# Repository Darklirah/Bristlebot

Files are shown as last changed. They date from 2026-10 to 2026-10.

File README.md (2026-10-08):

# One-of-a-Kind Mars Rover

> Dieses Projekt wurde mit Unterstützung von [Claude Code](https://claude.com/claude-code) entwickelt.

Linienfolgender, programmierbarer Zahnbürsten-Roboter auf ESP32, aufgebaut
auf einer eigenen Platine. Jedes Exemplar bekommt einen eigenen Namen und
ein eigenes WLAN (`MarsRover_Petra`), damit mehrere nebeneinander fahren
können.

> **Verwandt mit dem Bristlebot.** Der Mars Rover fährt nach demselben
> Prinzip wie ein *Bristlebot* — jener kleine Vibrationsläufer aus einem
> Zahnbürstenkopf, einem Unwuchtmotor und einer Knopfzelle, der über den
> Tisch summt. Er kann nur deutlich mehr: **zwei** Antriebe statt einem,
> damit er überhaupt lenken kann, zwei Augen für die Linie unter sich,
> Steuerung vom Handy und selbst geschriebene Fahrprogramme. Ein Bristlebot
> fährt, wohin er will — dieser hier fährt, wohin du willst.

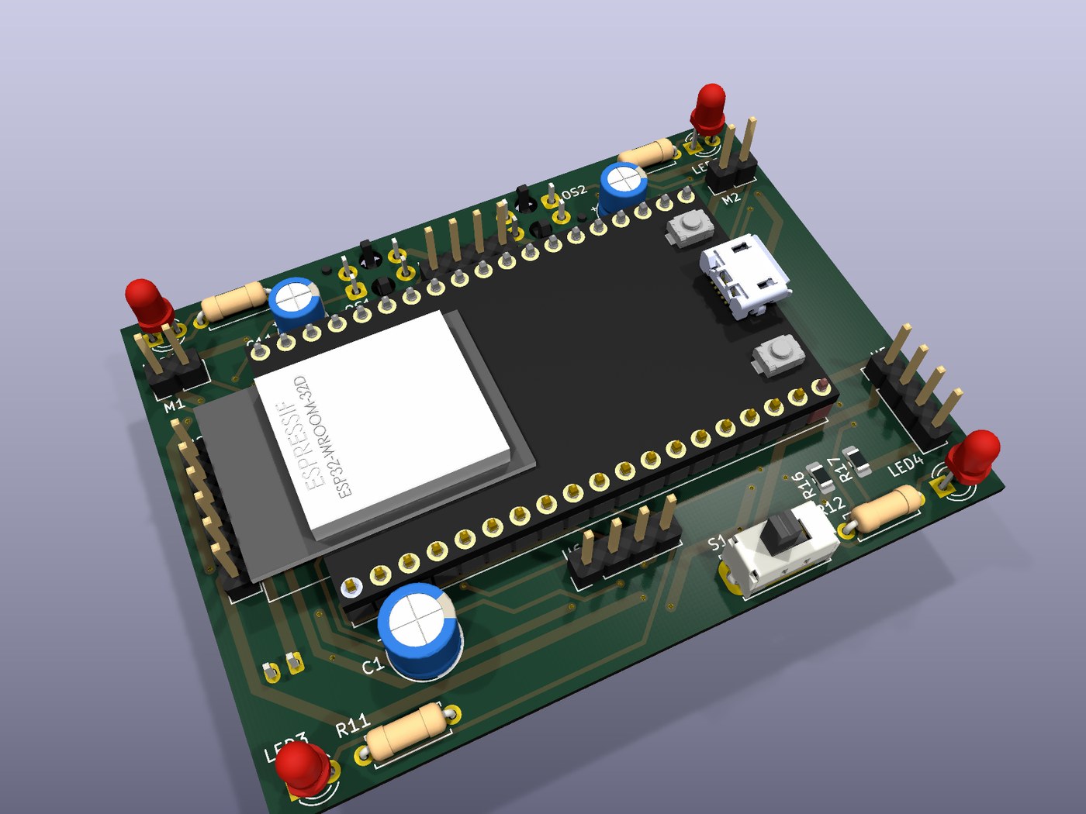
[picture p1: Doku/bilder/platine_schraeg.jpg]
Die fertig geroutete Platine, schräg von oben


*Die eigene Platine, 70 × 52 mm, zweilagig. Das ESP32-DevKit steckt quer auf
Buchsenleisten; links und rechts stehen Laderegler und Step-Up-Wandler
senkrecht als „Finnen". Weitere Ansichten mit Erklärung in
[Doku/04 §7](Doku/04_PCB-Layout-Empfehlung.md#7--so-ist-sie-geworden).*

**[→ Firmware direkt im Browser installieren](https://darklirah.github.io/One-of-a-Kind-Mars-Rover/)**

Die ausführliche Projektbeschreibung samt Programmier-Kapitel steht in
[Doku/00_Projektbeschreibung.md](Doku/00_Projektbeschreibung.md).

Zwei Vibrationsmotoren treiben zwei getrennte Borstenfelder an;
differentielle Vibrationsintensität lenkt. Zwei Reflexkoppler lesen die Linie,
ein PD-Regler hält ihn darauf. Gesteuert wird er über einen WLAN-Access-Point,
den der ESP32 selbst aufspannt — die Bedienoberfläche liefert er gleich mit.

**Status:** Hardware entworfen und geprüft, Firmware vollständig und
**fehlerfrei kompiliert** (0 Fehler, 0 Warnungen mit `-Wall`;
RAM 15,2 %, Flash 69,8 %) — **aber noch nie auf echter Hardware gelaufen.**

---

## Eckdaten

| | |
|---|---|
| Rechenkern | ESP32 DevKit V1, 30-Pin, gesteckt |
| Antrieb | 2× Vibrationsmotor 3 V über AO3400A Logik-MOSFET, 20 kHz PWM (LEDC) |
| Sensorik | 2× TCRT5000 analog an ADC1 (GPIO 34/35) |
| Lage | MPU-6050 am I²C: Drehen nach Winkel, Kurs halten, Kippschutz |
| Abstand | VL53L0X auf einem Mast: Hindernisse erkennen und umfahren |
| Anzeige | 4 LEDs: gelb vorne = Lenkrichtung, rot hinten = Status |
| Energie | LiPo 500 mAh, TP4056 über USB-C, MT3608 auf 5 V |
| Laufzeit | ≈ 1,2 h fahrend, ≈ 2,0 h Standby |
| Betriebsarten | Linie folgen · selbst fahren · Fahrprogramm |
| Fahrprogramme | 4 Speicherplätze im Flash, je 48 Schritte, Baukasten-Editor |
| Fernsteuerung | WLAN-AP + eigene Web-App, läuft auf iPhone **und** Android im Browser |
| Materialkosten | ≈ 26,50 € im Einzelstück |
| Masse | ≈ 40 g (größtes technisches Risiko, siehe Doku) |

## Bedienung in drei Schritten

1. Einschalten
2. Am Handy ins WLAN **`MarsRover_…`**, Passwort **`marsrover`**
3. Die Seite klappt von selbst auf — falls nicht: **`http://192.168.4.1`**

Nach dem Einschalten ist der Roboter **gesperrt**. Erst *Freigeben* in der App
lässt die Motoren laufen.

---

## Dokumentation

| Datei | Inhalt |
|---|---|
| [00 Projektbeschreibung](Doku/00_Projektbeschreibung.md) | Was das Projekt ist, alle Funktionen, ausführliches Kapitel zum Programmieren |
| [01 Schaltplan-Review](Doku/01_Schaltplan-Review.md) | Prüfung des Entwurfs: 5 Blocker, 9 Verbesserungen, Änderungsliste |
| [02 SMD vs. THT](Doku/02_SMD-vs-THT-Wirtschaftlichkeit.md) | Kostenvergleich bei 1/10/100 Stück, Massebudget, Laufzeitrechnung |
| [03 Stückliste](Doku/03_Stueckliste-BOM.md) | Vollständige BOM mit Bauteilkürzeln, Preisen und Einkaufsfallen |
| [04 PCB-Layout](Doku/04_PCB-Layout-Empfehlung.md) | Fertigungsparameter, Masseführung, Platzierung, Mechanik |
| [05 Pinbelegung](Doku/05_Pinbelegung.md) | Pinplan mit Begründungen, freie Pins, Vorzeichenkonventionen |
| [06 Fernsteuerung](Doku/06_Fernsteuerung-App.md) | Warum WLAN und nicht Bluetooth, Protokoll, fertige Apps als Rückfallebene |
| [07 Inbetriebnahme](Doku/07_Inbetriebnahme-und-Tuning.md) | Schrittweiser Aufbau, Kalibrierung, Reglerabstimmung, Fehlersuche |
| [Netzliste](Hardware/Netzliste.md) | Verbindungsliste als Vorlage für KiCad |
| [Projekt-Log](00_Projekt-Log.md) | Entscheidungen und offene Punkte |

## Firmware

```
Firmware/
  platformio.ini
  MarsRover/
    MarsRover.ino       Zustandsmaschine, PD-Regler, Telemetrie
    Config.h            Pins, Kennwerte, Feature-Flags  <- hier tunen
    RobotState.h        Betriebsart, Phase, Tuningstruktur
    Motors.*            PWM, Kennlinienspreizung, Kickstart, Duty-Begrenzung
    LineSensor.*        Median-Filter, Kalibrierung in NVS
    Leds.*              Blinkmuster
    RemoteControl.*     Access Point, Webserver, WebSocket, Protokoll
    WebUI.h             Bedienoberfläche, komplett inline
```

**Einzige externe Abhängigkeit:** `WebSockets` von Markus Sattler
(„arduinoWebSockets") ≥ 2.4.1. Läuft mit ESP32-Arduino-Core 2.x und 3.x — die
umgestellte LEDC-API wird per `#if` abgefangen.

Board: *ESP32 Dev Module*, 4 MB Flash, Partition *Default 4MB with spiffs*.

---

## Die wichtigsten vier Warnungen

1. **MT3608 vor dem ersten Anschluss des ESP32 im Leerlauf auf 5,00 V trimmen.**
   Die Module kommen mit beliebiger Einstellung, oft über 20 V. Das tötet das
   DevKit sofort.
2. **R_prog am TP4056 tauschen** — Werkszustand 1 A ist für eine 500-mAh-Zelle
   mehr als das Doppelte des Zulässigen. 4,7 kΩ ergibt 255 mA.
3. **USB-C braucht 2× 5,1 kΩ an CC1 und CC2 nach GND**, sonst liefert ein
   USB-C-Netzteil keine Spannung.
4. **Zwei getrennte Borstenfelder, eines unter jedem Motor.** Auf einer
   gemeinsamen Grundplatte mittelt sich die Vibrationsdifferenz weg und der
   Roboter lenkt praktisch nicht.

## Lizenz

[GNU General Public License v3.0](LICENSE)

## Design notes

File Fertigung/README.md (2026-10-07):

# Fertigungsdaten

**Alles in diesem Ordner ist erzeugt.** Die Quelle ist `pcb/MarsRover.kicad_pcb`.
Nach jeder Änderung an der Platine neu erzeugen:

```bash
bash Fertigung/erzeuge_fertigungsdaten.sh
```

Sonst liegen hier Gerber, die nicht mehr zur Platine passen — das ist der
klassische Weg, eine falsche Platine zu bestellen.

Stand: 07.10.2026, DRC 0 Fehler, 0 unverbundene Elemente.

---

## 1 · Was wohin gehört

| Datei | Wofür |
|---|---|
| `MarsRover-gerber.zip` | **Das lädst du beim Leiterplattenhersteller hoch.** Enthält alle Gerber, beide Bohrdateien und die Bohrpläne |
| `MarsRover-pastenschablone.zip` | Für den Schablonenhersteller: `F_Paste` + `Edge_Cuts` als Gerber, dazu DXF und SVG |
| `MarsRover-stueckliste.csv` | Einkaufsliste, nach Wert und Bauform gruppiert |
| `MarsRover-bestueckung.csv` | Bestückungsdaten (Referenz, Wert, Bauform, X, Y, Drehung, Seite) — nur nötig, wenn du maschinell bestücken lässt |
| `MarsRover-platine.step` | 3D-Modell der **nackten** Platine für den Entwurf des Basismoduls |
| `gerber/`, `pastenschablone/` | derselbe Inhalt unverpackt, zum Nachsehen |

Das vollständige 3D-Modell **mit** Bauteilen liegt unter
`local_Step Files/MarsRover-komplett.step` und bleibt lokal: es enthält
Fremdmodelle aus den KiCad- und Espressif-Bibliotheken, die nicht unsere zum
Weitergeben sind.

---

## 2 · Bestellparameter

| | |
|---|---|
| Lagen | **2** |
| Maße | **70 × 52 mm** |
| Dicke | **1,0 mm** — nicht 1,6 mm, das spart gut 4 g, und Masse ist auf diesem Gerät das Hauptproblem |
| Kupfer | 35 µm (1 oz) |
| Dünnste Leiterbahn | **0,40 mm** |
| Kleinster Abstand | **0,20 mm** |
| Durchkontaktierungen | 91 Stück: 0,8/0,4 mm (88×), 0,7/0,4 (2×), 0,6/0,4 (1×) |
| Kleinste Bohrung | **0,40 mm** (Durchkontaktierungen), 0,75 mm bei Bauteilen |
| Nicht durchkontaktierte Löcher | 6 (Mechanik von OS1/OS2 und S1) |
| Oberfläche | **noch nicht entschieden** — siehe unten |
| Lötstopp / Siebdruck | freie Wahl, elektrisch egal |
| Masseanbindung | **Wärmefallen**, Spalt 0,4 mm, vier Stege à 0,5 mm |

Diese Werte liegen alle im **Standardprozess** der günstigen Fertiger; nichts
davon löst einen Aufpreis aus.

> **Eine Entscheidung steht noch aus: die Oberfläche.** HASL ist am billigsten,
> ENIG kostet wenige Euro mehr und hat eine ebene Oberfläche. Auf dieser
> Platine sitzen 21 SMD-Bauteile, die über eine Pastenschablone bestückt
> werden — dafür ist eine ebene Fläche besser, weil HASL eine unregelmäßig
> dicke Lotbeule auf jedem Pad hinterlässt und die Schablone darauf kippelt.
> Bei 0805 und SOT-23 geht beides; bei ENIG geht es sicherer.

---

## 3 · Pastenschablone

Nur für die **Oberseite**. Auf der Unterseite sitzen nur die beiden TCRT5000
und der Akkustecker, und die sind bedrahtet — `B_Paste` ist deshalb leer.

- **44 Öffnungen**, verteilt auf 21 Bauteile: 9 Kondensatoren und 10
  Widerstände in 0805, 2 MOSFET in SOT-23.
- Rahmenlos bestellen (Framework/Frameless), Dicke **0,12 mm**. Das ist für
  0805 und SOT-23 der übliche Wert; dünner braucht man erst ab 0,5-mm-Raster.

---

## 3a · Wärmefallen an der Massefläche

Die Massefläche auf B.Cu hängt **nicht fest** an den Pads, sondern über
Wärmefallen: sie hält 0,4 mm Abstand zum Pad und greift mit vier Stegen von
0,5 mm Breite darauf zu.

**Warum:** eine 70 × 52 mm große Kupferfläche zieht beim Handlöten die Wärme
schneller ab, als ein Lötkolben sie nachliefert. Das Ergebnis sind kalte
Lötstellen, die beim Messen oft noch leitend wirken und erst bei Vibration
ausfallen — auf diesem Gerät also garantiert.

**Elektrisch kostet das nichts:** vier Stege à 0,5 mm auf 35 µm tragen
zusammen rund 6 A. Der größte Verbraucher auf dieser Masse ist der Step-Up
mit knapp 0,8 A Eingangsstrom, und der hat zwei Pads. Faktor fünfzehn Reserve.

Betroffen sind die **20 bedrahteten** Masse-Pads, die die Fläche direkt
berühren: C1, C11, C12, J2, LED1–LED4, OS1, OS2, U1 (Pins 14/32/38),
U2 (3×), U5 (2×), U6, U7.

Die **16 SMD-Masse-Pads** auf der Oberseite (C2–C10, Q1, Q2, R3, R4, R7, R8,
R17) berühren die Fläche gar nicht — sie hängen über eine kurze Leitung und
eine Durchkontaktierung daran. Dort gibt es nichts zu entlasten, und die
dünne Via-Hülse leitet ohnehin kaum Wärme ab.

---

## 4 · Nullpunkt

Gerber, Bohrdaten und Bestückungsliste benutzen **denselben, absoluten
Nullpunkt** (die Blattkoordinaten von KiCad). Das ist die Bedingung dafür,
dass der Fertiger die drei übereinanderlegen kann. Wenn ein Hersteller einen
Hilfsnullpunkt in einer Platinenecke verlangt, muss er für **alle drei**
Ausgaben umgestellt werden, nicht nur für eine.

---

## 5 · Was das DRC noch meldet, und warum es so bleibt

| Meldung | Anzahl | Warum das in Ordnung ist |
|---|---|---|
| `courtyards_overlap` | 21 | Alle unter U1. Das DevKit steckt auf Buchsenleisten gut 8,5 mm über der Platine; darunter liegt absichtlich alles Flache |
| `pth_inside_courtyard` | 4 | Die Pads von D1/D2, gleicher Grund |
| `lib_footprint_mismatch` | 4 | **Gewollte Abweichungen:** U1 trägt ein 3D-Modell, das die Bibliothek nicht hat, M1/M2 ein Feld „Hinweis" mit der Lötaugen-Begründung. Ohne Auswirkung auf die Fertigung — die Gerber kommen aus der Platinendatei, nicht aus der Bibliothek |

---

## 6 · Vor dem Bestellen prüfen

- [ ] **Reihenabstand des DevKits mit dem Messschieber nachmessen.** Soll:
      **25,4 mm**. Die 30-polige Version hat ein anderes Rastermaß, dann passt
      die Platine nicht. Siehe [Doku/09](../Doku/09_Boardwahl-DevKitC-V4.md)
- [ ] Oberfläche entscheiden (Abschnitt 2)
- [ ] Gerber in einem Betrachter gegenlesen — der Fertiger prüft nicht mit
- [ ] **MT3608 umbauen, bevor er eingelötet wird:** Poti raus, 110 kΩ / 15 kΩ
      rein. Siehe [Doku/07 Schritt 1a](../Doku/07_Inbetriebnahme-und-Tuning.md)

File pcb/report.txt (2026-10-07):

Hinweis: Footprint R1 (Resistor_SMD:R_0805_2012Metric_Pad1.20x1.40mm_HandSolder) aktualisiert: : (keine Änderungen)
Hinweis: Footprint R2 (Resistor_SMD:R_0805_2012Metric_Pad1.20x1.40mm_HandSolder) aktualisiert: : (keine Änderungen)
Hinweis: Footprint R3 (Resistor_SMD:R_0805_2012Metric_Pad1.20x1.40mm_HandSolder) aktualisiert: : (keine Änderungen)
Hinweis: Footprint R4 (Resistor_SMD:R_0805_2012Metric_Pad1.20x1.40mm_HandSolder) aktualisiert: : (keine Änderungen)
Hinweis: Footprint R5 (Resistor_SMD:R_0805_2012Metric_Pad1.20x1.40mm_HandSolder) aktualisiert: : (keine Änderungen)
Hinweis: Footprint R6 (Resistor_SMD:R_0805_2012Metric_Pad1.20x1.40mm_HandSolder) aktualisiert: : (keine Änderungen)
Hinweis: Footprint R7 (Resistor_SMD:R_0805_2012Metric_Pad1.20x1.40mm_HandSolder) aktualisiert: : (keine Änderungen)
Hinweis: Footprint R8 (Resistor_SMD:R_0805_2012Metric_Pad1.20x1.40mm_HandSolder) aktualisiert: : (keine Änderungen)
Hinweis: Footprint R16 (Resistor_SMD:R_0805_2012Metric_Pad1.20x1.40mm_HandSolder) aktualisiert: : (keine Änderungen)
Hinweis: Footprint R17 (Resistor_SMD:R_0805_2012Metric_Pad1.20x1.40mm_HandSolder) aktualisiert: : (keine Änderungen)

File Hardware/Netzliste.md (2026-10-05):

# Netzliste

Vollständige Verbindungsliste als Vorlage für die Schaltplaneingabe in KiCad.
Bauteilkürzel wie in der [Stückliste](../Doku/03_Stueckliste-BOM.md).

---

## Netze

### `VBAT` — Akkuspannung, 3,0 … 4,2 V

| Von | Nach |
|---|---|
| BT1 (+) über J2 Pin 1 | U2 `BAT+` |
| U2/U3-Schutzausgang `OUT+` | S1 Pin 2 (Mitte) |
| S1 Pin 1 | U5 `VIN+` |

### `+5V` — Ausgang des Step-Up

| Von | Nach |
|---|---|
| U5 `VOUT+` | U1 `VIN` |
| U5 `VOUT+` | C1 (+), C2 |
| U5 `VOUT+` | D3 Kathode *(optional, Zener 5,6 V)* |
| U5 `VOUT+` | M1 Anschluss A |
| U5 `VOUT+` | M2 Anschluss A |

> Revision laut [Review B2](../Doku/01_Schaltplan-Review.md): M1/M2 stattdessen
> an `VBAT` anschließen und in `Config.h` `MOTOR_SUPPLY_V = 4.2f` setzen.

### `+3V3` — bordeigener Regler des DevKits

| Von | Nach |
|---|---|
| U1 `3V3` | R5, R6 (Vorwiderstände der IR-LEDs) |
| U1 `3V3` | OS1 Kollektor, OS2 Kollektor |

### `GND`

Sternpunkt am Minuspol des Akkus bzw. am GND von U5. Drei getrennte Abgänge,
Begründung in der [Layout-Empfehlung §2](../Doku/04_PCB-Layout-Empfehlung.md):

| Abgang | Angeschlossen |
|---|---|
| **Leistung** | Emitter Q1, Emitter Q2, C1 (−), C2, C3, C4 |
| **Logik** | U1 `GND` (mindestens 2 Pins), U2/U3/U4 GND, U5 GND, S1-Gehäuse |
| **Sensorik** | R7, R8, OS1 Anode, OS2 Anode, R9–R12 (LED-Kathoden) |

---

## Ladeschaltung

| Netz | Verbindung |
|---|---|
| `USB_VBUS` | J1 VBUS (A4, A9, B4, B9) → U2 `VCC` |
| `USB_CC1` | J1 A5 → R13 → GND |
| `USB_CC2` | J1 B5 → R14 → GND |
| `PROG` | U2 `PROG` → R15 (4,7 kΩ) → GND |
| `BAT` | U2 `BAT` → U3 `VDD`, BT1 (+) |
| Schutzkette | U3 `OD`/`OC` → Gates von U4; U4 Source-Paar in der Minusleitung der Zelle |

> Beim **Fertigmodul (BOM 2b)** entfallen J1, R13, R14, U3 und U4 — sie sind
> enthalten. Nur R_prog muss getauscht werden.

---

## Motorzweig links (rechts identisch mit R2/R4/Q2/D2/C4/M2)

| Von | Nach |
|---|---|
| U1 `GPIO32` | R1 (100 Ω) |
| R1 | Q1 Gate |
| Q1 Gate | R3 (100 kΩ) → GND |
| `+5V` | M1 Anschluss A |
| M1 Anschluss B | Q1 Drain |
| M1 Anschluss B | D1 **Kathode** |
| M1 Anschluss A | D1 **Anode** |
| Q1 Drain | C4 (100 nF) → GND |
| Q1 Source | GND (Leistungsabgang) |

> D1 liegt **in Sperrrichtung parallel zum Motor**: Kathode an die Seite, die
> zum Drain geht, Anode an +5 V. Im Betrieb sperrt sie, beim Abschalten
> übernimmt sie den Induktionsstrom.

---

## Sensorzweig links (rechts identisch mit R6/R8/OS2)

| Von | Nach |
|---|---|
| `+3V3` | R5 (150 Ω) |
| R5 | OS1 IR-LED **Anode** |
| OS1 IR-LED **Kathode** | GND (Sensorabgang) |
| `+3V3` | OS1 Fototransistor **Kollektor** |
| OS1 Fototransistor **Emitter** | U1 `GPIO34` |
| OS1 Fototransistor **Emitter** | R7 (10 kΩ) → GND |

Emitterfolger-Schaltung: die Spannung an GPIO 34 steigt mit der einfallenden
IR-Menge. Heller Untergrund = hoher ADC-Wert, schwarze Linie = niedriger Wert.

**TCRT5000-Pinbelegung:** die vier Beine sind von außen nicht eindeutig
beschriftet. Das klare Gehäuse ist die IR-LED, das schwarze/dunkle der
Fototransistor. Vor dem Einlöten mit der Dioden-Messfunktion prüfen: die LED
zeigt ≈ 1,1 V in Vorwärtsrichtung, der Fototransistor in beiden Richtungen
nichts.

---

## LEDs

| GPIO | Widerstand | LED | Position |
|---|---|---|---|
| 14 | R9 220 Ω | LED1 gelb | vorne links |
| 27 | R10 220 Ω | LED2 gelb | vorne rechts |
| 26 | R11 220 Ω | LED3 rot | hinten links |
| 25 | R12 220 Ω | LED4 rot | hinten rechts |

Jeweils GPIO → Widerstand → LED-Anode, LED-Kathode → GND (Sensorabgang).

---

## Optional

| Netz | Verbindung | Aktivierung |
|---|---|---|
| Akkumessung | `VBAT` → R16 (100 kΩ) → Knoten → R17 (100 kΩ) → GND; Knoten → U1 `GPIO39`, dazu 100 nF nach GND | `FEATURE_BATTERY_MONITOR 1` |
| Modustaster | U1 `GPIO4` → SW2 → GND | `FEATURE_MODE_BUTTON 1` |

---

## Nicht belegte DevKit-Pins

`EN`, `GPIO36`, `GPIO12`, `GPIO13`, `GPIO23`, `GPIO22`, `GPIO21`, `GPIO19`,
`GPIO18`, `GPIO17`, `GPIO16`, `GPIO5`, `GPIO4`, `GPIO2`, `GPIO15`, `TX0`, `RX0`

`GPIO12` und `GPIO13` bleiben bewusst frei — Begründung in der
[Pinbelegung](../Doku/05_Pinbelegung.md). `TX0`/`RX0` sind von der
USB-Konsole belegt.

---

## I²C-Bus (Nachtrag: Lage- und Abstandssensor)

Beide Sensoren teilen sich einen Bus. Die Adressen kollidieren nicht.

| Netz | Verbindung |
|---|---|
| `SDA` | U1 `GPIO21` → U6 `SDA`, U7 `SDA` |
| `SCL` | U1 `GPIO22` → U6 `SCL`, U7 `SCL` |
| `+3V3` | U1 `3V3` → U6 `VCC`, U7 `VIN` |
| `GND` | Sensorabgang → U6 `GND`, U7 `GND` |

| Sensor | Adresse | Platz |
|---|---|---|
| U6 · MPU-6050 (GY-521) | `0x68` (AD0 offen/GND) | flach auf dem Chassis |
| U7 · VL53L0X (GY-530) | `0x29` | auf dem Mast, nach vorn blickend |

**Pull-ups:** beide Breakouts bringen eigene 4,7-kΩ-Pull-ups auf SDA und SCL
mit. Zwei Module parallel ergeben also rechnerisch 2,35 kΩ — bei 400 kHz
völlig unkritisch, es sind keine weiteren Widerstände nötig. Kommt ein
drittes Modul dazu, auf einem die Pull-ups auslöten.

**Nicht belegt:** `AD0` (Adresswahl des MPU-6050), `INT` beider Module,
`XSHUT` des VL53L0X. XSHUT bräuchte man nur, wenn ein zweiter VL53L0X
dazukäme — zwei Sensoren haben dieselbe feste Adresse und müssen beim Start
nacheinander aufgeweckt und umadressiert werden.

### Mast

| | |
|---|---|
| Werkstoff | CFK-Rundstab Ø 3 mm |
| Länge | ca. 60 mm über der Platine |
| Position | vorn mittig, zwischen den beiden TCRT5000 |
| Blickrichtung | waagerecht nach vorn, **nicht** zum Boden geneigt |
| Befestigung | in eine Ø-3,2-mm-Bohrung geklebt, zusätzlich mit Heißkleber verkeilt |

**Kabelführung:** die vier Litzen **verdrillt** am Mast entlangführen und am
Fuß eine kleine Schlaufe lassen. Ein straff gespanntes Kabel an einem
vibrierenden Mast bricht an der Lötstelle — die Schlaufe nimmt die Bewegung
auf. Mit zwei Tropfen Heißkleber am Mast fixieren, nicht an der Platine
ziehen lassen.

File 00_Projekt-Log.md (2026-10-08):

# Projekt-Log: One-of-a-Kind Mars Rover

Laufendes Protokoll. Neueste Einträge oben.

## 2026-10-08 — Befehlsauswahl mit eigener Liste (Firmware 0.2.1)

Die Gruppen *Fahren / Zeit / Licht / Ablauf* steckten in einem nativen
`<select>`. Dessen `optgroup`-Beschriftungen zeichnet das **Betriebssystem**:
Android und iOS öffnen einen eigenen Auswahldialog, der jede Formatierung
der Seite ignoriert. Per CSS wäre „hellgelb und fett" dort nie angekommen.

**Deshalb eine selbst gebaute Liste:**

- Das `<select>` bleibt als Datenspeicher stehen, nur ausgeblendet — alles
  andere liest unverändert `E("aOp").value`, kein Risiko an den drei
  Stellen, die davon abhängen.
- Die sichtbare Liste **erzeugt sich aus eben diesem `<select>`**. Die
  Befehle stehen weiter nur an einer Stelle im Markup; ein neuer Eintrag
  taucht automatisch an der richtigen Stelle auf.
- Gruppenüberschrift 15 px fett in `#ffe08a`, der gewählte Befehl blau
  hervorgehoben statt in einem zugeklappten Feld zu verschwinden.

**Geprüft:** fünf Befehle quer durch alle vier Gruppen angeklickt, jedes Mal
kommt der richtige Wert an und es erscheinen genau die passenden
Einstellfelder.

**Bewusst in Kauf genommen:** die Liste ist immer ausgeklappt, gut 600 px
statt eines zugeklappten Feldes. Dafür ist alles auf einen Blick sichtbar.

Firmware **0.2.1** gebaut und veröffentlicht: RAM 15,2 %, Flash 70,4 %.
Online gegengeprüft — das Abbild auf GitHub Pages ist bitgleich mit dem
gebauten (995 440 Byte).

**Nachtrag am selben Tag: die Bildschirmfotos sind da.** Die Rückfrage hat
sich erledigt — gemeint war die Oberfläche. [Doku/06](Doku/06_Fernsteuerung-App.md)
hat jetzt einen Abschnitt „So sieht sie aus" mit **vier** Aufnahmen:
Hauptansicht mit Joystick, Namensabfrage, Programmeditor mit den drei
farbigen Bereichen und die Befehlsliste mit den Gruppenüberschriften. Sie
entstehen aus `.preview/index.html` und sind mit einem Lauf neu erzeugt,
falls sich an der Oberfläche noch etwas ändert.

## 2026-10-08 — Firmware 0.2.0 gebaut und für den Installer bereitgelegt

**Gebaut:** `pio run -e esp32dev_core2`, sauberer Durchlauf von Null.
**0 Fehler, 0 Warnungen** mit `-Wall`. RAM 15,2 %, Flash **70,3 %**
(vorher 69,8 % — die neue Oberfläche kostet gut 6 kB).

**Zwei Hürden, beide auf diesem Rechner, beide jetzt im Skript abgefangen**

1. **TLS.** Der Build brach mit `CERTIFICATE_VERIFY_FAILED` ab: zwischen
   PlatformIO und GitHub sitzt ein Scanner, der TLS aufbricht, und dessen
   Wurzelzertifikat kennt Pythons `requests` nicht. `UV_SYSTEM_CERTS` half
   nicht — das gilt nur für `uv`, hier scheiterte PlatformIOs eigener
   Download. Gelöst, ohne die Prüfung abzuschalten: aus dem
   Windows-Zertifikatsspeicher wird ein Bündel erzeugt (81 Zertifikate,
   dazu `certifi`) und über `REQUESTS_CA_BUNDLE` untergeschoben.
2. **Cache-Pfad.** `PLATFORMIO_CACHE_DIR='C:\pioc'` legt unter Git Bash
   einen relativen Ordner `Firmware/pioc/` an statt `C:\pioc` zu benutzen.
   Mit Vorwärtsschrägstrichen stimmt es.

**Neues Skript
[`Firmware/baue_und_veroeffentliche.sh`](Firmware/baue_und_veroeffentliche.sh)**

Zwischen „kompiliert" und „mit dem Installer installierbar" liegen zwei
Schritte, die man leicht vergisst. Das Skript nimmt sie mit:

| Offset | Teil |
|---|---|
| `0x01000` | Bootloader |
| `0x08000` | Partitionstabelle |
| `0x0e000` | `boot_app0` |
| `0x10000` | die Anwendung |

Das `manifest.json` nennt **einen** Teil bei Offset 0 — also muss alles in
ein zusammengefügtes Abbild. Nur `firmware.bin` hochzuladen hieße: Gerät
ohne Bootloader, bootet nicht mehr. Dazu zieht das Skript auf Wunsch die
Version im Manifest nach.

**Ergebnis:** `docs/firmware/marsrover-esp32.bin`, 993 376 Byte, Aufbau
Byte für Byte gegen das bisher veröffentlichte Abbild geprüft.
Manifest auf **0.2.0**.

> **Sichtbar wird das erst nach einem Push.** Der Installer liest die
> Dateien von `darklirah.github.io`.

## 2026-10-08 — Der Roboter heißt überall Mars Rover

Bisher stand „Bristlebot" verstreut in Doku, Firmware und Ordnernamen, weil
der Begriff am 05.10. ausdrücklich als Bauartbezeichnung stehenbleiben
sollte. **Diese Regel ist aufgehoben.** Der Begriff steht jetzt nur noch in
**je einem erklärenden Absatz** in [README](README.md) und
[Doku/00](Doku/00_Projektbeschreibung.md), der die Verwandtschaft nett und
verständlich beschreibt — mit einer kleinen Gegenüberstellung, was der Mars
Rover mehr kann. Überall sonst heißt er Mars Rover.

**Umbenannt**

| vorher | nachher |
|---|---|
| `Firmware/bristlebot/` | `Firmware/MarsRover/` |
| `bristlebot.ino` | `MarsRover.ino` |
| `src_dir = bristlebot` in `platformio.ini` | `src_dir = MarsRover` |
| Kopfkommentare in 12 Firmware-Dateien | auf `MarsRover` |
| Pfadangaben in Doku 05, 06, 07 und README | auf den neuen Ordner |

> **Für den nächsten Build:** der Ordnername hat sich geändert, PlatformIO
> baut deshalb einmal komplett neu. `Firmware/.pio/` darf dafür weg, muss
> aber nicht — es ist ohnehin gitignoriert.
>
> Der Ordnername musste mitwandern, weil die Arduino IDE verlangt, dass
> Ordner und `.ino`-Datei gleich heißen.

**Zwei echte Fehler gefunden, nicht nur Namen**

Beim Durchgehen fiel auf, dass die Dokumentation an zwei Stellen ein
**Passwort nannte, das die Firmware gar nicht mehr benutzt**:

| Stelle | stand da | richtig ist |
|---|---|---|
| [Doku/06 §Benutzung](Doku/06_Fernsteuerung-App.md) | WLAN `Bristlebot`, Passwort `bristlebot` | WLAN `MarsRover_…`, Passwort `marsrover` |
| [docs/index.html](docs/index.html) (Web-Installer) | Passwort `bristlebot` | Passwort `marsrover` |

In `Config.h` steht seit Längerem `AP_PREFIX = "MarsRover"` und
`AP_PASSWORD = "marsrover"`. Wer sich an die Doku gehalten hätte, wäre nicht
ins WLAN gekommen. Ebenfalls nachgezogen: das Code-Beispiel in Doku/06 zeigte
noch ein `AP_SSID`, das es nicht mehr gibt, und die erwartete
Konsolenausgabe in [Doku/07](Doku/07_Inbetriebnahme-und-Tuning.md).

**Nicht angefasst: die älteren Einträge in diesem Log.** Das Repo hieß
damals wirklich `Darklirah/Bristlebot` und das Verzeichnis `Bristlebot/` —
ein Protokoll, das rückwirkend umgeschrieben wird, ist als Protokoll
wertlos. Der Eintrag vom 05.10., der die alte Regel festlegte, hat einen
Nachtrag bekommen, der auf ihre Aufhebung verweist.

---

## 2026-10-07 — Wärmefallen an der Massefläche

Die Massefläche hing **fest** an den Pads (`connect_pads yes`, vom Router so
gesetzt). Eine 70 × 52 mm große Kupferfläche zieht beim Handlöten die Wärme
schneller ab, als ein Lötkolben sie nachliefert — das Ergebnis sind kalte
Lötstellen, die beim Messen oft noch leitend wirken und erst bei Vibration
ausfallen. Auf diesem Gerät also garantiert.

Umgestellt auf **Wärmefallen**: Spalt 0,4 mm, vier Stege à 0,5 mm. Die
vorhandenen Werte waren mit je 0,2 mm zu knapp und wurden ohnehin nicht
benutzt.

| | |
|---|---|
| Betroffen | die **20 bedrahteten** Masse-Pads, die die Fläche direkt berühren |
| Nicht betroffen | die **16 SMD-Masse-Pads** auf der Oberseite — sie hängen über eine kurze Leitung und eine Durchkontaktierung an der Fläche, berühren sie also gar nicht |
| Elektrisch | vier Stege à 0,5 mm auf 35 µm tragen zusammen rund 6 A. Größter Verbraucher ist der Step-Up mit knapp 0,8 A, und der hat zwei Pads — Faktor fünfzehn Reserve |
| Geprüft | DRC 0 unverbundene Elemente, 0 Abstandsverstöße. Das B.Cu-Gerber wuchs um 38 KB, genau die zusätzliche Geometrie der Freistellungen |

Fertigungsdaten neu erzeugt — das B.Cu-Gerber hat sich geändert.

---

## 2026-10-07 — Siebdruck aufgeräumt, Fertigungsdaten erzeugt

**Bestückungsdruck: von 96 Verstößen auf null**

| | vorher | nachher |
|---|---|---|
| `silk_overlap` | 60 | **0** |
| `text_height` | 32 | **0** |
| `silk_over_copper` | 4 | **0** |
| `silk_edge_clearance` | 0 | **0** |

Drei Eingriffe:

1. **45 Wertefelder ausgeblendet.** Der Wert steht in der Stückliste; auf dem
   Siebdruck kostet er nur Platz. Das Wertefeld von U1 lag auf dem Pad von C7.
2. **Die 38 Pinnamen des DevKitC-Footprints auf F.Fab verschoben.** Sie stehen
   auf 2,54 mm Raster, sind 0,7 mm hoch — unter der 0,8-mm-Regel — und jeder
   Name ist länger als sein Rastermaß. Gedruckt gäbe das einen Schmierer, und
   das aufgesteckte Modul deckt sie ohnehin zu; auf dem Modul selbst stehen
   dieselben Namen lesbar drauf. Auf F.Fab bleiben sie in der
   Bestückungszeichnung erhalten.
3. **Alle 45 Referenzen** auf 0,8 mm gesetzt und neu platziert. Die Suche
   probiert ein dichtes Raster um das Bauteil, nach Abstand sortiert, und
   nimmt den nächstgelegenen Platz, der weder ein Pad noch eine andere
   Siebdruckspur noch den Platinenrand berührt. Feste Ringe reichten nicht:
   in den Ecken sprang ein 0,4-mm-Schritt über die letzte Lücke hinweg.

**Drei Durchkontaktierungen vergrößert**, von 0,5/0,3 auf 0,7/0,4 — 0,1 mm
Restring war die Untergrenze der günstigen Fertiger. Eine davon musste bei
0,6/0,4 bleiben, sonst kam sie einer Signalleitung auf 0,175 mm nahe.

**Fertigungsdaten unter [`Fertigung/`](Fertigung/README.md)**

Gerber (9 Lagen), beide Bohrdateien mit Bohrplänen, Stückliste,
Bestückungsdaten, Pastenschablone (nur Oberseite, 44 Öffnungen auf 21
Bauteile — unten sitzt kein SMD) und das STEP-Modell der nackten Platine.
Erzeugt von [`erzeuge_fertigungsdaten.sh`](Fertigung/erzeuge_fertigungsdaten.sh),
damit es nach jeder Platinenänderung wiederholbar ist.

Das vollständige STEP **mit** Bauteilen (23 MB) bleibt lokal unter
`local_Step Files/` — es enthält Fremdmodelle aus den KiCad- und
Espressif-Bibliotheken.

**Offen: die Oberfläche.** HASL oder ENIG ist noch nicht entschieden. Bei 21
SMD-Bauteilen über eine Pastenschablone spricht einiges für ENIG, weil HASL
eine ungleichmäßige Lotbeule auf jedem Pad hinterlässt und die Schablone
darauf kippelt.

---

## 2026-10-07 — U5 blockierte den USB; Routingwerkzeug dauerhaft eingerichtet

**Gemacht**

- **U5 an die Hinterkante.** Pad 1 von U1 ist 3V3 (Antennenende), Pad 19 ist
  5V — der Micro-USB sitzt also am +x-Ende bei x ≈ 154, mittig auf der
  Modulbreite bei y = 85. U5 stand mit y 81,2…88,8 **genau davor**. Jetzt
  y 97,0…104,62, Gehäusevorderkante 95,2, gut 4 mm Luft zum Steckergehäuse.
- Dafür mussten **R16/R17** (Spannungsteiler VBAT → GPIO39) von x 156,5/160,5
  nach x 150/154 wandern. Als 0805 dürfen sie überall in den hinteren Streifen.
- Neu geroutet: 27/27 Netze, 91/91 Padpaare, 91 Durchkontaktierungen,
  **0 unverbundene Elemente, 0 Abstandsverstöße, 0 lose Leitungsenden**.

**Werkzeug dauerhaft eingerichtet** (gehört in die HowTo-Datei)

| | |
|---|---|
| CLI + Quelle | `C:\Users\Frank-PC-AMD\Tools\KiCadRoutingTools` |
| KiCad-Plugin | `~\Documents\KiCad\10.0\3rdparty\plugins\KiCadRoutingTools` |
| Aufruf in KiCad | **Tools → External Plugins → KiCadRoutingTools** |
| Nachinstalliert in KiCads Python | `scipy`, `shapely` (numpy und Pillow waren da) |

Damit lässt sich das Routing auch **aus dem offenen PCB-Editor heraus**
starten — das Ergebnis steht danach direkt im Editor, mit Undo.

---

## 2026-10-07 — Platine geroutet: 27 von 27 Netzen, null unverbundene Elemente

**Gemacht**

- Platzierung nachgezogen: J2 als **liegender** Stecker
  (`JST_PH_S2B-PH-K_1x02_P2.00mm_Horizontal`) auf die **Unterseite**, weil der
  Akku unter die Platine kommt und ein stehender Stecker in den 5-mm-Spalt
  ragen würde; OS1/OS2 auf optimalen Abstand; U6 hinten mittig; S1 daneben.
- **Geroutet** mit [KiCadRoutingTools](https://github.com/drandyhaas/KiCadRoutingTools)
  (A\*-Router mit Rust-Kern, MIT, headless auf der `.kicad_pcb`).
  Ergebnis: **27/27 Netze, 91/91 Padpaare, 101 Durchkontaktierungen,
  0 unverbundene Elemente, 0 Abstandsverstöße, 0 Kurzschlüsse.**
- Massefläche auf **B.Cu**, eine zusammenhängende Insel, 1,0 mΩ über 86 mm.

**Entscheidungen**

- **Sensorabstand OS1/OS2:** Die Fototransistoren zeigen nach innen und stehen
  12,5 mm auseinander. Maßgeblich ist aber der **optische Messfleck**, der
  jeweils mittig zwischen LED und Transistor liegt — die stehen damit
  **18 mm** auseinander und liegen im von [Doku/04](Doku/04_PCB-Layout-Empfehlung.md)
  geforderten Fenster 15–20 mm für ein 19-mm-Band.
- **Kein Ausschnitt für den MPU-6050.** Ein Gyroskop misst die Drehrate eines
  starren Körpers an jedem Punkt gleich; nur der Beschleunigungsmesser sieht
  Zentrifugalterme, und die betragen bei 180 °/s und 30 mm Abstand 0,03 g —
  zwei Größenordnungen unter der Motorvibration. Ein 22 × 17-mm-Loch mitten in
  einer 1 mm dünnen Platte hätte also Steifigkeit und Massefläche gekostet,
  ohne messbar etwas zu bringen. Damit ist Regel 1 aus Doku/04 §6 („nahe der
  Drehachse") die **schwächste** der drei; Regel 2 (weit weg von den Motoren)
  und Regel 3 (weich ankoppeln) bleiben.
- **Keine Durchkontaktierung in einem Pad.** Der erste Lauf setzte 16 Vias
  mitten in SMD-Pads. Das verlangt IPC-4761 Typ VII (gefüllt und überplattet);
  beim Handlöten saugt es sonst das Lot in die Hülse. Mit
  `--same-net-pad-clearance 0.2` sind es null.

**Zwei Fehlschläge, beide Platzierung statt Routing**

- R2 Pad 1 hatte links und rechts je **0,8 mm** Padabstand — genau die Breite,
  die eine 0,4-mm-Leitung mit zweimal 0,2 mm Abstand braucht, also null
  Spielraum. Daran scheiterten beide Router. R2 um 0,5 mm und Q2 um 0,6 mm
  nach außen hat es gelöst. *(Erster Versuch mit 1 mm war zu viel und legte
  R2 Pad 2 auf das Massepad von Q2 — vom DRC gefunden.)*
- J2 deckte in der ersten Stellung die Unterseiten-Pads von LED3 und R11 ab.
  Auf der Unterseite ist das kein Gehäuse-, sondern ein **Löt**problem.

**Abweichungen von der Breitenvorgabe, bewusst**

| Netz | Soll | Dünnste Stelle | Länge dort |
|---|---|---|---|
| +5V | 1,0 mm | 0,40 mm | 10,3 von 194 mm |
| +3V3 | 0,8 mm | 0,40 mm | 5,6 von 177 mm |
| GND (Zuleitungen) | 1,0 mm | 0,33 mm | 33 von 66 mm |
| Net-(D1-A) | 1,0 mm | 0,40 mm | 15,7 von 35 mm |

Das sind **Einschnürungen am Pad**: eine 1-mm-Leitung passt nicht in ein
0805-Pad von 1,2 mm Breite, wenn der Nachbar 0,8 mm entfernt ist. 0,4 mm auf
35 µm tragen nach IPC-2221 **1,23 A** bei 10 K Erwärmung; die Motoren ziehen
zusammen rund 0,3 A. +3V3 wurde bewusst mit 0,8 statt 1,0 mm angefordert — es
trägt nur die Sensorik (gut 40 mA), und 1 mm hätte Querungen gefressen, die
die Signale brauchen.

**Offen**

- Siebdruck: 58 Überlappungen und 32 zu kleine Texte. Rein kosmetisch, aber
  vor der Bestellung aufzuräumen.
- 21 Courtyard-Überlappungen und 4 THT-Pads im Courtyard: alle unter dem
  gesockelten DevKit, also gewollt.

---

## 2026-10-07 — MT3608 bekommt einen Festteiler statt des Potis

**Gemacht**

- [Doku/07](Doku/07_Inbetriebnahme-und-Tuning.md): Schritt 1 in **1a und 1b**
  geteilt. 1a beschreibt den Modulumbau, 1b nur noch das Nachmessen.
- [Doku/03](Doku/03_Stueckliste-BOM.md): U5 ist jetzt als Umbauteil
  gekennzeichnet, die zwei Teilerwiderstände stehen als referenzlose Position
  in der Liste (sie gehören aufs Modul, nicht auf die Platine). Einkaufsfalle 3
  umformuliert.
- [Doku/04](Doku/04_PCB-Layout-Empfehlung.md): Siebdruck-Hinweis angepasst —
  „SET 5V0 neben dem Trimmer" stimmt nicht mehr, der Trimmer ist weg.

**Entscheidung: Trimmpoti am MT3608 auslöten, 110 kΩ / 15 kΩ einsetzen**

Zwei Gründe, der zweite ist der wichtigere:

1. Das Poti ist das höchste Bauteil des Moduls und steht im Weg, sobald das
   Modul als senkrechte Finne montiert wird.
2. Ein Schleifkontakt auf einem Fahrzeug, dessen Antriebsprinzip Vibration
   ist, verstellt sich. Verstellt er sich nach oben, hängt das DevKit an
   mehr als 5 V.

Gerechnet über die 0,6-V-Referenz des MT3608:
0,6 V × (1 + 110 kΩ / 15 kΩ) = 0,6 × 8,333 = **5,00 V**.

**Fallstrick, der dokumentiert ist:** Der werkseitige untere
Rückkopplungswiderstand des Moduls muss raus. Bleibt er liegen, steht er
parallel zu den 15 kΩ und die Ausgangsspannung steigt.

**Geprüft**

- Schaltplan nach der Nutzer-Bearbeitung gegengerechnet: Netzliste Knoten für
  Knoten gegen den Vorstand verglichen, **keine Abweichung außer den von mir
  nachträglich eingefügten Entkoppelkondensatoren**. ERC: 0 Fehler,
  2 bekannte kosmetische Warnungen an D1/D2.

---

## 2026-10-06 — Schaltplan neu aufgebaut: Bereiche und gezeichnete Leitungen

**Gemacht**

- Schaltplan vollstaendig neu aufgebaut, Blatt jetzt **A2** statt A3:
  **175 gezeichnete Leitungen, 25 Knotenpunkte, null Netzlabels**
- Fuenf beschriftete Bereiche: Rechenkern · Motortreiber · Sensoren
  Linienerkennung · Sensoren Lage und Abstand · Signal-LEDs · Akku und
  Ladevorrichtung
- Neues Werkzeug `pcb/build_schematic.py`. Die acht Lagen (vier Drehungen,
  zwei Spiegelungen) sind am lebenden KiCad **ausgemessen**, nicht geraten;
  das Skript prueft am Ende selbst, ob jede Koordinate auf dem
  1,27-mm-Raster liegt.
- `pcb/gen_schematic.py` ist **gesperrt** — ein Lauf bricht jetzt mit einer
  Meldung ab, statt den Schaltplan mit der alten Fassung zu ueberschreiben.
  Die Datei bleibt als Beleg der Netzliste liegen.
- Geprueft: ERC **0 Fehler**, keine verwaisten Leitungen, keine
  Ueberlappungen, Netzliste knotengenau gegen den Entwurf abgeglichen.
- Zwei echte Zeichenfehler gefunden und behoben: Leitungen liefen quer
  durch die Gehaeuse von U2 und U5 hindurch.

**Entscheidungen**

- **Keine MOSFETs fuer die LEDs.** Nachgesehen im ESP32-WROOM-32-Datenblatt
  v3.8, Tabelle 14: I_OH typisch **40 mA** je Pin in der Domaene
  VDD3P3_RTC, bei mehreren gleichzeitig treibenden Pins noch rund 29 mA
  (Fussnote 2). Alle vier LED-Pins — GPIO 14, 25, 26, 27 — liegen in dieser
  Domaene. Vorwiderstand bleibt **220 Ohm**, rund 5 mA je LED.
  Das spart zwoelf Bauteile auf einer Platine, deren groesstes Risiko die
  Masse ist. Die 40 mA gelten allerdings nur bei maximaler Treiberstaerke;
  die Voreinstellung von Arduino und ESP-IDF ist Stufe 2 mit etwa 20 mA.
- **Versorgung ueber Power-Symbole**, nicht als durchgezogene Leitung.
  GND, +5V und +3V3 quer ueber ein A2-Blatt zu ziehen waere unleserlicher,
  nicht lesbarer. Je Netz ein PWR_FLAG an der Quelle.
- **Netznamen** sind jetzt automatisch vergeben (`Net-(D1-A)` statt
  `MOT_L_D`). Fuer das Platinenlayout waeren sprechende Namen nuetzlich —
  ein Label auf einer bereits gezeichneten Leitung *benennt* nur, es
  *verbindet* nicht. Offen, siehe unten.
- Verbleibende Kreuzungen sind gewollt und ohne Knotenpunkt, also
  elektrisch nicht verbunden: zwei am I2C-Bus (bei zwei Teilnehmern an
  einem Zweidrahtbus nicht vermeidbar), zwei im Akkubereich, weil BAT+
  zwischen zwei Massepins des Lademoduls liegt.

**Offen**

- [ ] Sprechende Netznamen? Nur benennend, die Verdrahtung bleibt gezeichnet
- [ ] Zwei ERC-Warnungen `lib_symbol_mismatch` an D1/D2 — kosmetisch, Folge
      des Aufloesens der Symbolvererbung (1N5819 erbt von SB120)

**Als Naechstes**

Review durch den Nutzer in KiCad, dann das Platinenlayout.

---

## 2026-10-05 (7) — KiCad-MCP-Server, Schaltplan wird neu aufgebaut

**Gemacht**

- Schaltplan-Entwurf durchgesehen und **verworfen**: Bauteile wild über das
  Blatt verteilt, Verbindungen ausschließlich über Netzlabels
- [KiCAD-MCP-Server](https://github.com/mixelpixx/KiCAD-MCP-Server) v2.8.2
  (MIT) nach `C:\Users\Frank-PC-AMD\Tools\KiCAD-MCP-Server` installiert und
  in `~/.claude.json` unter dem Projekt „HA Claude" eingetragen.
  Geprüft: 244 Werkzeuge, `pcbnew 10.0.0` startet sauber
- KiCads Sperrdatei `*.lck` aus der Versionierung genommen — war versehentlich
  eingecheckt. Ebenso ignoriert: `.history/`, `pcb/Bilder/`

**Entscheidungen**

- **Der Schaltplan wird in Bereiche gegliedert:** Rechenkern, Motortreiber,
  Sensorik, Akku und Ladevorrichtung. Innerhalb der Bereiche **gezeichnete
  Leitungen**, keine Netzlabels. Vorgabe des Nutzers, nicht verhandelbar.
- **Werkzeugwechsel:** `pcb/gen_schematic.py` wird **nicht mehr ausgeführt**.
  Es erzeugt die Datei komplett neu und überschreibt damit jede Handarbeit.
  Es bleibt als Beleg der Netzliste liegen. Künftig gezielte Einzeleingriffe
  über den MCP-Server — dadurch überleben manuelle Änderungen im
  Schaltplaneditor.
- **Regel für die Zusammenarbeit an der Datei: immer nur einer schreibt.**
  Vor jedem Schreibzugriff wird geprüft, ob eine `*.lck` im `pcb/`-Ordner
  liegt; dann hat KiCad die Datei offen und sie wird nicht angefasst.
  Ungespeicherte Änderungen im Editor sind von außen unsichtbar — erst
  speichern, dann übergeben.
- KiCad **10** bleibt. Kein Wechsel auf 11: das ist derzeit ein Nightly, das
  Dateiformat ist eine Einbahnstraße, und das Platinenlayout läuft auf 10
  bereits live über die IPC-Schnittstelle.
- Der Review-Screenshot bleibt **lokal**, kommt nicht ins Repo.

**Offen — zum Projektabschluss, vom Nutzer bestellt**

- [ ] **HowTo-Datei** mit allen benutzten Schnittstellen und ihrer
      Einrichtung, damit Nachbauer dieselbe Umgebung herstellen können.
      Mindestens: PlatformIO samt der drei nötigen Umgebungsvariablen
      (`UV_SYSTEM_CERTS`, `UV_NATIVE_TLS`, `PLATFORMIO_CACHE_DIR`), der
      KiCAD-MCP-Server samt Konfiguration, ESP Web Tools und GitHub Pages,
      die Datenblattquellen aus [Doku/10](Doku/10_Datenblaetter.md)
- [ ] **Fertiger Prompt für Claude**, der alle benötigten Werkzeuge und
      Schritte ermöglicht, um diese Arbeiten durchzuführen — mit
      ausführlicher Erklärung jedes einzelnen Schritts. So geschrieben,
      dass jemand mit leerer Claude-Sitzung und leerem Rechner bis zum
      fahrenden Roboter kommt und dabei versteht, *warum* jeder Schritt
      nötig ist. Gehört mit der HowTo-Datei zusammen gedacht: die eine
      beschreibt die Umgebung, der andere setzt sie in Gang.

**Als Nächstes**

Schaltplan neu aufbauen, Bereich für Bereich, mit gezeichneten Leitungen.
Danach ERC, SVG zum Durchsehen, dann das Platinenlayout.

---

## 2026-10-05 (6) — MOSFET statt Bipolartransistor, Datenblätter, KiCad-Start

**Frage:** Wäre ein MOSFET als Ersatz für den BC337 nicht sinnvoller?

**Antwort: ja — aber nicht wegen des Wirkungsgrads.** Der entscheidende
Punkt ist der Spannungsabfall. Der BC337 frisst 0,25 V von der 5-V-Schiene,
das sind rund **8 % der Motorspannung**, die nicht in Vibration umgesetzt
werden. Bei einem Roboter, dessen größtes Risiko „zu schwer, fährt
vielleicht nur kriechend" lautet, wirkt das direkt auf die Schwachstelle.

**Entschieden: AO3400A** (SOT-23, 28 mΩ bei 4,5 V Gate, 5,7 A, ~10 ct).
Verworfen: IRLZ44N in TO-220 — elektrisch top, aber 2 g je Stück bei einem
Roboter, bei dem um Gramm gekämpft wird.

Gewarnt und dokumentiert: **2N7000, BS170 und IRF540 taugen hier nicht.**
Ihr R_DS(on) ist für 10 V Gate-Spannung spezifiziert; an 3,3 V sind sie kaum
durchgesteuert. Klassischer Anfängerfehler, steht jetzt in Review B10.

Nachgezogen: Stückliste, Netzliste (Gate/Drain/Source statt Basis/Kollektor/
Emitter), Pinbelegung, Layoutempfehlung, Datenblattliste, README und das
Generator-Skript. Gate-Widerstand 100 Ω statt 1 kΩ, Pulldown 100 kΩ statt
10 kΩ. **Die Firmware ändert sich nicht.**

**Datenblätter.** `docs/` ist der von GitHub Pages veröffentlichte Ordner,
keine Dokumentenablage — das dort abgelegte AZ-Datenblatt ist nach
`Datasheets/` gewandert und per `.gitignore` aus dem Repo gehalten.
Stattdessen eine Linkliste ([Doku 10](Doku/10_Datenblaetter.md)): jeder kommt
an jedes Dokument, und zwar an die aktuelle Fassung beim Hersteller statt an
eine eingefrorene Kopie.

**KiCad.** Live-Verbindung zur laufenden Instanz steht (IPC-API, `kipy`).
Ordner `pcb/` mit eigener Bibliothek (TCRT5000-Symbol, von KiCad geprüft)
und der offiziellen Espressif-Bibliothek. Generator-Skript für den
Schaltplan angelegt, Stufe 1 (Rechenkern + Motorstufe) ist beschrieben.

**Nächster Schritt:** Generator laufen lassen, Format gegen ERC prüfen, dann
die restlichen rund 30 Bauteile ergänzen.

---

---

## 2026-10-05 (5) — Umbenannt, kompiliert, Web-Installer

**Projekt heißt jetzt „One-of-a-Kind Mars Rover".** „Bristlebot" bleibt in
der Technikdoku als Bezeichnung der Bauart stehen.

> *Nachtrag vom 08.10.2026: diese Regel ist aufgehoben. Der Begriff steht
> jetzt nur noch in je einem erklärenden Absatz in README und
> Projektbeschreibung, sonst heißt der Roboter überall Mars Rover.*

**Erfolgreich kompiliert — erstmals.**

```
RAM:   15.2 % (49.784 von 327.680 Bytes)
Flash: 69.8 % (914.437 von 1.310.720 Bytes)
0 Fehler, 0 Warnungen (mit -Wall)
```

Gebaut gegen `espressif32@6.9.0` (offizielle Plattform, Arduino-Core 2.x),
neue Umgebung `esp32dev_core2` in der `platformio.ini`. Damit ist auch der
Core-2.x-Pfad der Firmware bestätigt.

**Drei Hürden auf dem Weg dahin — alle in der Umgebung, keine im Code:**

1. **`uv` lehnt GitHub-Zertifikate ab** (`invalid peer certificate:
   UnknownIssuer`), während `curl` dieselbe Adresse mit HTTP 200 erreicht.
   Klassische Signatur eines TLS-aufbrechenden Virenscanners oder Proxys.
   Abhilfe: `UV_SYSTEM_CERTS=1` **und** `UV_NATIVE_TLS=1` (ältere
   uv-Versionen kennen nur die zweite). Die Plattform verschluckt den
   Fehler zusätzlich, weil sie die uv-Ausgabe nach DEVNULL wirft.
2. **Windows-Pfadgrenze**, exakt 260 Zeichen erreicht beim Entpacken von
   `esp32-arduino-libs`. `LongPathsEnabled` steht auf 0. Abhilfe ohne
   Registry-Eingriff: `PLATFORMIO_CACHE_DIR=C:\pioc`.
3. **Der pioarduino-Fork** (Plattform 55.03.37) scheitert reproduzierbar an
   seiner penv-Einrichtung, auch nachdem die Pakete manuell erfolgreich
   installiert wurden. Deshalb der Ausweichweg über die offizielle
   Plattform. Ungeklärt, aber umgangen.

**Neu: eindeutiger Netzname je Gerät.** Ab Werk `MarsRover_<MAC-Kennung>`,
damit mehrere Rover nebeneinander funktionieren, ohne dass jemand etwas
einstellt. Im Experten-Bereich lässt sich ein eigener Name vergeben
(`MarsRover_Petra`), gespeichert im NVS, aktiv nach einem Neustart, den die
Oberfläche gleich mit auslöst. Neue Protokollbefehle `N|<name>` und `Z`.

**Neu: Web-Installer.** `docs/` enthält eine Installationsseite mit ESP Web
Tools, `manifest.json` und die zusammengeführte Binärdatei
(`marsrover-esp32.bin`, 986 KB, Offset 0x0). GitHub Pages muss noch
eingeschaltet werden. Web Serial gibt es nur in Chrome, Edge und Opera auf
dem Desktop — nicht auf Handys, nicht in Firefox und Safari.

**Neu: `Doku/00_Projektbeschreibung.md`** — ausführliche Beschreibung des
Projekts und aller Funktionen, mit einem langen Kapitel zum Programmieren
(Zeitmodell, alle Befehle, Vorgehen, vier Beispiele vom Lichtspiel bis zum
selbsttätigen Ausweichen, typische Fehler, Grenzen).

**Nächste Sitzung:**

- [ ] GitHub Pages einschalten, Installationsseite prüfen
- [ ] Repo und lokalen Ordner auf `One-of-a-Kind-Mars-Rover` umbenennen
- [ ] 3D-Basismodul entwerfen — Anforderungen stehen in
      [Doku 00 §8](Doku/00_Projektbeschreibung.md). **Platine und Basismodul
      gehören zusammen entworfen**, der endgültige Platinenumriss ist bis
      dahin offen
- [ ] Bauanleitung mit Bildern, entsteht beim Bau des ersten Exemplars
- [ ] Teile bestellen, aufbauen, Funktionstest fahren

---

## 2026-10-05 (4) — Stromversorgung geprüft, LiPo bestätigt

**Frage:** Spart ein Halter mit Schalter für 3× AAA plus Buck-Boost Gewicht?

**Antwort: nein, er kostet ~36 g.** 3× AAA samt Halter wiegen ≈ 52 g gegen
≈ 14 g der LiPo-Lösung; die Gesamtmasse stiege von ~45 g auf ~85 g. Dazu
schlechtere Energiedichte (doppelte Energie für 3,7-fache Masse) und
0,9 Ω Innenwiderstand in Reihe, was bei den 1-A-Spitzen des ESP32 um 0,9 V
einbricht. Vollständige Rechnung in [Doku 02 §7](Doku/02_SMD-vs-THT-Wirtschaftlichkeit.md).

**Entscheidung des Auftraggebers:** LiPo bleibt wie geplant. Über den
**Buck-Boost direkt auf 3,3 V** (≈ 90 % statt ≈ 56 % Wirkungsgrad, rund ein
Drittel mehr Laufzeit, kein Mehrgewicht) wird erst entschieden, **wenn der
erste Aufbau fährt** — die Massefrage ist bislang gerechnet, nicht gemessen.

**Nicht erledigt, bewusst offen:**

- [ ] Buck-Boost auf 3,3 V nach dem ersten Fahrversuch bewerten. Haken dabei:
      Rückwärtseinspeisung in den AMS1117 des DevKits, USB und Akku dürfen
      dann nicht gleichzeitig anliegen
- [ ] Sicherheitsvorgabe für den Aufbau: geschützte Zelle, vollständig im
      Gehäuse, keine freien Kontakte, Laden nicht unbeaufsichtigt

---

---

## 2026-10-05 (3) — Lagesensor und Abstandssensor

**Frage des Auftraggebers:** Bringt ein MPU-6050 Genauigkeit? Und wäre ein
GY-511 (LSM303DLHC) auf einem Mast wie bei Curiosity besser?

**Antwort und Entscheidung**

- MPU-6050: **ja, für Drehungen — nein, für Strecken.** Zweifache Integration
  der Beschleunigung ist auf einem vibrationsgetriebenen Roboter binnen ein
  bis zwei Sekunden unbrauchbar.
- LSM303DLHC **abgelehnt**: hat kein Gyroskop, sondern Beschleunigung +
  Magnetometer. Für „drehe um 90°" braucht es die Drehrate. Der Mast wäre
  physikalisch richtig gedacht (Störfeld fällt mit 1/r³, 20 → 80 mm sind
  64× weniger), löst aber ein Problem, das bei Manövern von Sekunden gar
  nicht auftritt: die Gyro-Drift liegt dabei unter 1°.
- Stattdessen: **MPU-6050 flach aufs Chassis + VL53L0X auf den Mast.** Der
  ToF-Sensor verträgt die Mastschwingung, weil er über sein Messfenster
  mittelt — ein Magnetometer dagegen verlöre dort seine Ausrichtung, und
  die ist bei einem Kompass die Messgröße.

**Umgesetzte Funktionen** (vom Auftraggeber ausgewählt)

Lagesensor: Drehen nach Winkel · Geradeauslauf halten · Kipp- und
Aufheb-Erkennung. Kursgeführte Liniensuche wurde verworfen.
Abstandssensor: fahren bis Hindernis · drehen bis frei · warten bis frei,
dazu ein abschaltbarer Hindernis-Stopp als Schutzfunktion.

**Gebaut**

- `Imu.*` — MPU-6050 ohne Fremdbibliothek. DLPF auf 21 Hz und Messbereiche
  bewusst grob (±8 g), weil ein übersteuernder MEMS-Sensor unter Vibration
  einen Gleichanteil erzeugt, der wie echte Neigung aussieht
- `Distance.*` — VL53L0X über die Pololu-Bibliothek. Gelesen wird nur, wenn
  der Chip ein Ergebnis gemeldet hat, sonst würde der Lesebefehl bis zu
  33 ms in der Hauptschleife stehen
- vier Warte-Flags im Interpreter zu **einem** Zustand `Await`
  zusammengefasst, bevor die Zustandsmaschine unübersichtlich wurde
- Funktionstest um beide Sensoren erweitert — er dreht sich dabei selbst
  einmal nach rechts und einmal nach links und prüft damit auch die
  **Drehrichtung** des Kreisels. Ein um 180° verdreht montierter Sensor
  fällt sonst erst beim ersten Fahrprogramm auf und sieht dort wie ein
  Programmierfehler aus
- Urteile im Klartext unter dem Testknopf

**Beide Sensoren sind optional.** Fehlen sie, läuft alles weiter: Drehbefehle
fallen auf eine Zeitschätzung zurück, Abstandsbefehle enden nach ihrer
Zeitgrenze. Die Oberfläche sagt das auch.

**Massefolge:** +4,5 g auf ~45 g, davon 2 g oben auf dem Mast. Das verschärft
das Hauptrisiko aus Doku 02 §4. Die dortige Abspeckliste holt ~6,5 g zurück.

**Weiterhin ungetestet** — nichts davon lief je auf Hardware.

---

---

## 2026-10-05 (2) — Fahrprogramm und Funktionstest

**Entscheidungen (vom Auftraggeber bestätigt)**

| Frage | Entscheidung |
|---|---|
| Zeitmodell | eigener `warte`-Befehl; Fahrbefehle setzen nur den Zustand |
| Kurvenradius | Stufe 1 = engste Kurve, Stufe 10 = weite Kurve |
| Speicherung | vier Slots im ESP32-Flash, je 48 Schritte |
| Editor | Baukasten mit Auswahlfeldern, kein Texteditor |
| Geschwindigkeit | **am Fahrbefehl**, kein eigener Tempo-Befehl (Korrektur im Nachgang) |
| Oberfläche | einfach bedienbar, geeignet ab 14 Jahren |

**Gebaut**

- `Program.*` — Parser mit Klartext-Fehlermeldungen, vier NVS-Slots,
  Interpreter mit Schrittbudget gegen Blockieren der Hauptschleife
- `SelfTest.*` — eingebauter Funktionstest: LEDs einzeln, alle blinkend,
  Motor links und rechts als Rampe. Bewusst **kein** Fahrprogramm: einzelne
  Motoren und Rampen lassen sich mit der Programmsprache nicht ausdrücken,
  und ein Diagnosewerkzeug soll keinen Speicherplatz belegen
- `Leds.*` um Override erweitert; Sicherheitsanzeigen behalten Vorrang
- dritter Modus in `bristlebot.ino`, neue Protokollbefehle `B`, `L`, `W`, `S`
- Oberfläche: drei Betriebsarten, Baukasten-Editor mit Schrittzähler je
  Slot, Farbcodierung, grüne Markierung des laufenden Schritts,
  Experten-Bereich zugeklappt
- Beispielprogramm „Achter" wird beim ersten Start automatisch angelegt
- Doku 08 neu, 06 und 07 nachgezogen

**Methodik**

Die Oberfläche wurde vor dem Festschreiben mit einem Daten-Stub im Browser
gerendert und am Bildschirm abgenommen (`.preview/`, gitignoriert).

**Weiterhin ungetestet** — nichts davon lief je auf Hardware.

---

## 2026-10-05 — Entwurf geprüft, Firmware und Doku gebaut

**Entscheidungen (vom Auftraggeber bestätigt)**

| Frage | Entscheidung | Verworfene Alternativen |
|---|---|---|
| Fernsteuerung | WLAN-AP + eigene Web-App | BLE + fertige App (Dabble/Bluefruit); beides parallel |
| Liniensensorik | 2× TCRT5000 analog | 1× Fototransistor; 5-Kanal-Array |
| ESP32-Bauform | DevKit 30-Pin THT, gesteckt | ESP32-WROOM-32E SMD; ESP32-C3-MINI-1 SMD |

**Geprüft und geändert** (Details: [Doku/01](Doku/01_Schaltplan-Review.md))

Fünf Blocker im Ausgangsentwurf:

1. `BluetoothSerial` ist klassisches SPP und auf iOS ohne MFi-Lizenz nicht
   nutzbar → WLAN-AP
2. dem Fototransistor fehlte die beleuchtende IR-LED → TCRT5000
3. ein einzelner Sensor kann nicht differentiell lenken → zwei Sensoren
4. GPIO 12 ist Strapping-Pin MTDI und kann das Booten verhindern → Motoren auf
   GPIO 32/33
5. USB-C ohne 2× 5,1 kΩ an CC1/CC2 bekommt keine 5 V → nachgetragen

Dazu neun Verbesserungen: Basis-Pulldowns gegen Motorzucken beim Booten,
Schottky statt 1N4148, zusätzliche Entkopplung, R_prog an die Zellgröße,
Akku 500 statt 150 mAh, Schalterposition hinter dem Ladepfad, Duty-Begrenzung
für 3-V-Motoren an der 5-V-Schiene.

**Gebaut**

- Firmware, modular: `Config.h`, `RobotState.h`, `Motors.*`, `LineSensor.*`,
  `Leds.*`, `RemoteControl.*`, `WebUI.h`, `bristlebot.ino`
- Web-App komplett inline im Flash (kein CDN — im AP-Betrieb gibt es kein
  Internet), Captive Portal, Totmannschalter, Live-Tuning, Telemetriebalken
- Doku 01–07 plus Netzliste als KiCad-Vorlage
- `platformio.ini` als Alternative zur Arduino IDE

**Bewusst offengelassen**

- Motoren hängen wie vom Auftraggeber entworfen an der **5-V-Schiene**. Die
  bessere Variante (an VBAT, entlastet den knappen MT3608 um 1 W und hält die
  Motorspitzen aus der ESP32-Versorgung) ist dokumentiert und in `Config.h` eine
  Zeile — aber nicht eigenmächtig umgesetzt, weil es den Schaltplan ändert.
- Der 56-%-Wirkungsgrad des Pfads MT3608 → AMS1117 bleibt. Abhilfe wäre ein
  3,3-V-Buck-Boost, der aber das Auslöten des bordeigenen Reglers erfordert.

**Größtes Risiko**

Masse ≈ 40 g. Funktionierende Bristlebots liegen bei 10–25 g. Es wird fahren,
aber kriechen, und die Lenkautorität ist bei hoher Masse gering. Abspeckliste
in [Doku/02 §4](Doku/02_SMD-vs-THT-Wirtschaftlichkeit.md); sofort umsetzbar
und kostenlos: PCB in 1,0 mm statt 1,6 mm bestellen, LEDs 3 mm statt 5 mm.

**Nichts davon ist in Hardware getestet.**

**Nächste Schritte**

- [ ] Teile bestellen (Stückliste [Doku/03](Doku/03_Stueckliste-BOM.md))
- [ ] Firmware einmal probeweise kompilieren, damit die Toolchain-Seite geklärt ist
- [ ] Schaltplan und Layout in KiCad zeichnen, Vorlage: [Netzliste](Hardware/Netzliste.md)
- [ ] Entscheidung Motoren an VBAT statt 5 V
- [ ] Inbetriebnahme nach [Doku/07](Doku/07_Inbetriebnahme-und-Tuning.md),
      Schritt für Schritt — nicht alles auf einmal einschalten
- [ ] Bewährte Kp/Kd/Grundvibration in `Config.h` zurückschreiben

---

## 2026-10-05 — Projekt angelegt

**Gemacht**

- Verzeichnis `Bristlebot/` im Ordner „HA Claude" erstellt
- Grundgerüst: `README.md`, `00_Projekt-Log.md`, `.gitignore`, `LICENSE` (GPL-3.0)
- Öffentliches GitHub-Repo `Darklirah/Bristlebot` angelegt und ersten Commit gepusht

**Entscheidungen**

- Sichtbarkeit: **öffentlich**, wie die anderen Projekte
- Lizenz: **GPL-3.0**
- Struktur: zunächst nur Grundgerüst, Projektart offen gelassen

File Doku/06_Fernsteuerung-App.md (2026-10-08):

# Fernsteuerung und App

Anforderung: Steuerung muss **auf Android und iPhone** funktionieren.

---

## 1 · Warum es nicht BluetoothSerial geworden ist

`BluetoothSerial` im ESP32-Arduino-Core ist klassisches Bluetooth **SPP** (Serial
Port Profile). Apple gibt SPP auf iOS für Fremdgeräte nicht frei — dafür braucht
man eine MFi-Lizenz und einen Apple-Authentifizierungschip im Gerät. Auf Android
funktioniert SPP tadellos, auf dem iPhone grundsätzlich nicht.

Es bleiben damit genau zwei plattformübergreifende Wege: **BLE** oder **WLAN**.

| | WLAN-AP + eigene Web-App | BLE + fertige App |
|---|---|---|
| iPhone | ✅ Browser | ✅ |
| Android | ✅ Browser | ✅ |
| Installation nötig | **keine** | App aus dem Store |
| Oberfläche gestaltbar | **vollständig** | nur was die App anbietet |
| Telemetrie zurück | **beliebig** (Sensorbalken, Hz, Akku) | Textzeilen |
| Live-Tuning (Kp, Kd, Schwellen) | **ja, mit Schiebereglern** | nur über Zahleneingabe |
| Mehrverbrauch | ≈ 80 mA | ≈ 15 mA |
| Handy bleibt im Heim-WLAN | nein | ja |

**Gewählt: WLAN-AP mit eigener Web-App.** Der Mehrverbrauch kostet rund 20 %
Laufzeit, dafür gibt es eine passgenaue Oberfläche, Live-Telemetrie und
Reglerabstimmung im Betrieb — und null Installationsaufwand auf fremden Geräten.

---

## 2 · Die gebaute Web-App

Der ESP32 spannt einen eigenen Access Point auf und liefert die Oberfläche selbst
aus. Quelle: [`Firmware/MarsRover/WebUI.h`](../Firmware/MarsRover/WebUI.h),
Serverlogik in [`RemoteControl.cpp`](../Firmware/MarsRover/RemoteControl.cpp).

### Benutzung

1. Roboter einschalten.
2. Am Handy ins WLAN **`MarsRover_…`** verbinden, Passwort **`marsrover`**.
3. Die Bedienseite klappt meist von selbst auf (Captive-Portal-Erkennung).
   Falls nicht: Browser öffnen, **`http://192.168.4.1`** eingeben.

> Auf dem iPhone meldet iOS „Kein Internet" — das ist korrekt, der Roboter hat
> keine Internetverbindung. Die Meldung bestätigen und im Netz bleiben.
> Reagiert der Joystick im automatisch aufklappenden Fenster nicht, dieses
> Fenster schließen und die Seite in Safari direkt über die IP aufrufen. Das
> Portal-Fenster von iOS ist eine eingeschränkte WebView.

### So sieht sie aus

Vier Bildschirmfotos sagen mehr als die Tabelle darunter. Sie stammen aus
der Vorschaufassung mit eingespeisten Beispieldaten — der Aufbau ist
derselbe, den die Firmware ausliefert.

#### Selbst fahren

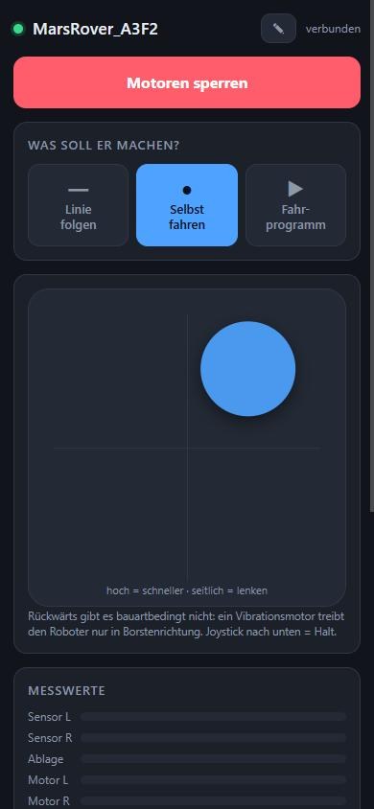
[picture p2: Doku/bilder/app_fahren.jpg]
Hauptansicht mit Joystick


Die Startansicht. Oben der Netzname des Roboters und der Statuspunkt, dann
der große Freigabeknopf — der ist **rot, solange die Motoren freigegeben
sind**, und beschriftet mit *Motoren sperren*. Darunter die Wahl der
Betriebsart, darunter das Joystickfeld: hoch ist schneller, seitlich lenkt.
Der Knopf folgt dem Finger bis an den Rand.

#### Dem Roboter einen Namen geben

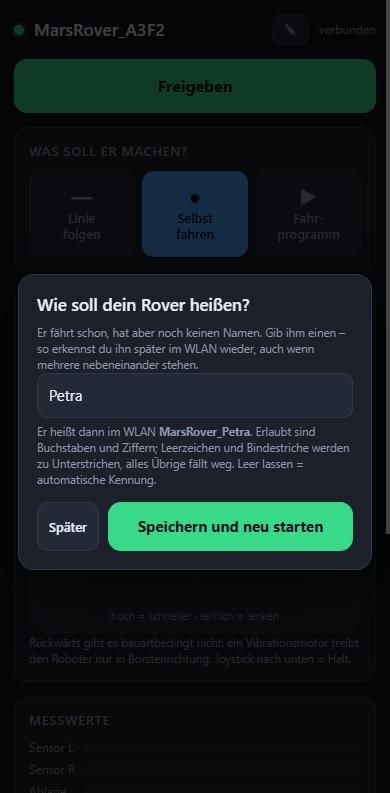
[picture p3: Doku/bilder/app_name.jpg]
Namensabfrage beim ersten Start


Dieses Fenster klappt beim ersten Start von selbst auf, später erreicht man
es über den Stiftknopf oben rechts. Unter dem Eingabefeld steht **live
mitgerechnet**, wie das WLAN danach heißt — hier `MarsRover_Petra`.

#### Fahrprogramm zusammenstellen

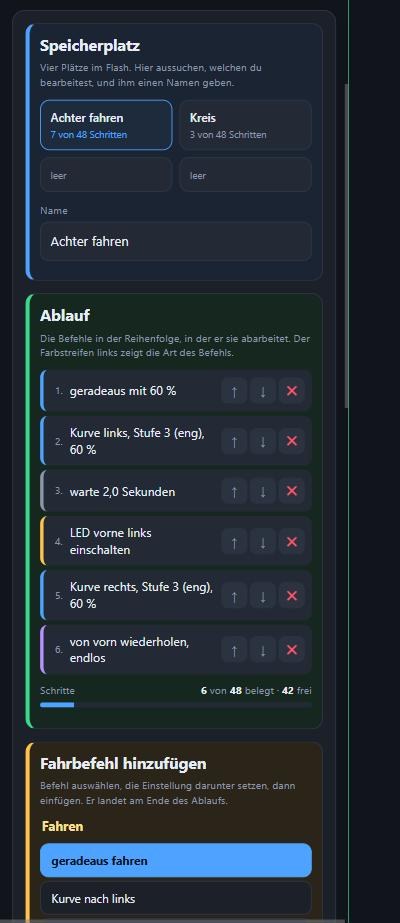
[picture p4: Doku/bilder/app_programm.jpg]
Programmeditor mit den drei Bereichen


Der Editor ist in drei farbige Bereiche geteilt, damit man auf dem Handy
nicht die Orientierung verliert: **blau** die Wahl des Speicherplatzes,
**grün** der Ablauf, **gelb** der Baukasten darunter. In der Schrittliste
zeigt ein Farbstreifen links die Art jedes Befehls — blau Fahren, grau
Warten, gelb Licht, violett Ablaufsteuerung. Unten der Schrittzähler.

#### Befehl aussuchen

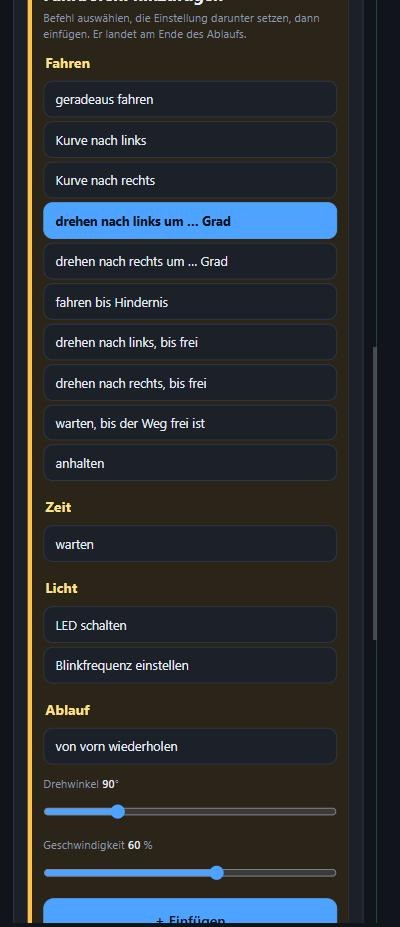
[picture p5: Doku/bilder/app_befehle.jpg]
Befehlsliste mit Gruppen


Die Befehle sind nach **Fahren, Zeit, Licht, Ablauf** gruppiert; die
Gruppenüberschriften stehen hellgelb und fett über ihren Einträgen. Der
gewählte Befehl ist blau hervorgehoben, und darunter erscheinen genau die
Einstellungen, die er braucht — beim Drehbefehl also Drehwinkel **und**
Geschwindigkeit.

> **Warum keine Auswahlliste:** die Gruppenüberschriften eines `<select>`
> zeichnet das Betriebssystem. Android und iOS öffnen einen eigenen Dialog,
> der jede Formatierung der Seite ignoriert — hervorheben ließe sich dort
> nichts. Die Liste ist deshalb selbst gebaut.

### Was die Oberfläche kann

| Element | Funktion |
|---|---|
| Statuspunkt oben | grün = WebSocket verbunden |
| **Freigeben / Motoren sperren** | Nach dem Einschalten ist der Roboter **gesperrt**. Ohne Freigabe läuft kein Motor — verhindert, dass er beim Einschalten vom Tisch fährt |
| Linie folgen / Selbst fahren / Fahrprogramm | Betriebsart. Beim Wechsel stoppen die Motoren immer erst, ein laufendes Programm wird beendet |
| Joystick | hoch = schneller, seitlich = lenken. Loslassen = Stillstand. Bei Stillstand und vollem Seitenausschlag: Drehen auf der Stelle |
| Grundgeschwindigkeit | Basisvibration im Linienfolger-Modus |
| Linie kalibrieren | 5-Sekunden-Kalibrierfahrt, Werte landen im NVS-Flash |
| Programm-Editor | Vier Speicherplätze, Baukasten statt Texteingabe, Schrittzähler. Siehe [08_Fahrprogramm.md](08_Fahrprogramm.md) |
| Sensorbalken L/R, Ablage | Live-Messwerte — das wichtigste Werkzeug beim Einrichten |
| Motorbalken L/R | tatsächlich ausgegebener PWM-Duty |
| Statuszeile | Phase, Kalibrierzustand, Schleifenfrequenz, ggf. Akkuspannung |
| **Experten** (zugeklappt) | Kp, Kd, Anlaufschwelle, Kalibrierung löschen — bewusst versteckt, damit beim Ausprobieren nichts versehentlich verstellt wird |
| **NOTHALT** | sperrt sofort, stoppt ein laufendes Programm und hebt die Freigabe auf |

### Gestaltungsvorgabe

Die Oberfläche ist auf **einfache Bedienbarkeit ab 14 Jahren** ausgelegt:
Klartext statt Kürzel (*„warte 2,0 Sekunden"*, nicht `wa,2000`), große
Tippflächen, Farbcodierung der Befehlsarten, und ein Baukasten, in dem
Syntaxfehler gar nicht erst entstehen können. Alles, was man zum Fahren
nicht braucht, liegt hinter dem zugeklappten Experten-Bereich.

### Technische Eckpunkte

* **Alles inline.** Kein CDN, keine Webfonts, kein externes Skript — im
  AP-Betrieb gibt es keinen Internetzugang, nachgeladene Ressourcen würden
  einfach fehlen.
* **WebSocket auf Port 81** für Steuerbefehle und Telemetrie; die Seite selbst
  kommt per HTTP von Port 80. Die App sendet mit 10 Hz, der Roboter antwortet
  mit ca. 6,7 Hz Telemetrie.
* **Totmannschalter.** Kommt im Handbetrieb länger als 500 ms kein Paket, stoppen
  die Motoren. Deckt abgeschaltetes Display, Browser im Hintergrund,
  weggelaufene WLAN-Verbindung und geschlossenen Tab ab.
* **Captive Portal per DNS.** Ein DNS-Server auf Port 53 löst jeden Namen auf
  192.168.4.1 auf, und der Webserver antwortet auf *jede* URL mit der App. Damit
  schlägt die Portalerkennung von iOS (`captive.apple.com`) und Android
  (`/generate_204`) an und das Bedienfenster öffnet sich selbst.
* **iOS-Safari-Eigenheiten berücksichtigt:** Pointer Events statt Touch Events,
  `touch-action: none` auf dem Joystickfeld, `overscroll-behavior: none` gegen
  das Gummiband-Scrollen, `gesturestart` und `dblclick` abgefangen gegen
  Pinch- und Doppeltipp-Zoom, `maximum-scale=1`.
* **Maximal 4 Clients**, Sendeleistung auf 11 dBm reduziert (spart Strom, im
  Zimmer mehr als ausreichend).

### Dem Roboter einen Namen geben

Der Rover hat keine Anzeige und keine Tasten — die Web-App ist die einzige
Stelle, an der er zu seinem Namen kommt.

**Beim ersten Start fragt die App von selbst.** Sobald sie sich verbindet und
feststellt, dass noch kein eigener Name gespeichert ist, klappt ein Fenster
auf: *„Wie soll dein Rover heißen?"* Wer das überspringen will, tippt auf
**Später** — dann bleibt es bei der automatischen Kennung aus den letzten vier
Stellen der MAC-Adresse (`MarsRover_A3F2`). Gefragt wird einmal je
Sitzung, nicht bei jedem Verbindungsabbruch.

**Später umbenennen** geht über den **Stiftknopf oben neben dem Namen** oder
über *Experten → Roboter umbenennen*. Beide öffnen dasselbe Fenster.

**Nach dem Speichern startet der Rover neu.** Das ist keine Schikane: den
WLAN-Namen vergibt der ESP32 beim Hochfahren in `softAP()`. Ohne Neustart
würde der Name zwar im Speicher stehen, das Netz aber bis zum nächsten
Einschalten noch alt heißen. Die App schickt deshalb `N|<name>` und direkt
nach der Quittung `Z`. **Danach am Handy ins neue WLAN wechseln.**

**Was aus der Eingabe wird**, zeigt das Fenster live mit: Umlaute werden
umgeschrieben (`Jürgen` → `MarsRover_Juergen`, `Groß` → `MarsRover_Gross`),
Leerzeichen und Bindestriche werden zu Unterstrichen, alles Übrige fällt
weg, und bei 16 Zeichen ist Schluss. Die Regel steht in `setApName()` in
[`RemoteControl.cpp`](../Firmware/MarsRover/RemoteControl.cpp) und ist in der
App Zeichen für Zeichen nachgebaut, damit die Vorschau nicht lügt.

> **Warum Umlaute umgeschrieben werden:** ein `ü` sind in UTF-8 zwei Bytes,
> und keines davon ist für sich genommen ein Buchstabe. Ohne die Umschrift
> fielen sie stillschweigend weg — aus `Jürgen` würde `Jrgen`.

### Passwort und SSID ändern

In [`Config.h`](../Firmware/MarsRover/Config.h):

```cpp
static const char AP_PREFIX[]   = "MarsRover";   // Netzname, MAC haengt hinten an
static const char AP_PASSWORD[] = "marsrover";   // min. 8 Zeichen!
```

WPA2 braucht mindestens 8 Zeichen. Ein leerer String gibt einen offenen AP —
dann klappt das Portal etwas zuverlässiger auf, aber jeder in Reichweite kann
den Roboter fahren.

---

## 3 · Protokoll

Textzeilen über den WebSocket, kommagetrennt. Dokumentiert, falls du später eine
native App, ein Skript oder eine Fernsteuerung mit echten Knöppen anbinden willst.

### App → Roboter

| Befehl | Bedeutung |
|---|---|
| `J,<x>,<y>` | Joystick, je −1 … +1. `y ≤ 0` heißt Halt |
| `M,0` / `M,1` / `M,2` | Betriebsart manuell / Linienfolger / Fahrprogramm |
| `A,0` / `A,1` | sperren / freigeben |
| `X` | Nothalt |
| `C` | Kalibrierfahrt starten |
| `R` | Kalibrierung löschen |
| `T,<kp>,<kd>,<base>,<min>` | Tuningwerte setzen (werden 1,5 s später ins NVS gesichert) |
| `P` | Ping, hält den Totmannschalter wach |
| `B,0` / `B,1` | Fahrprogramm stoppen / starten. Starten schaltet zugleich auf `M,2` |
| `L,<slot>` | Speicherplatz 0–3 laden, Antwort `prog` |
| `W,<slot>|<name>|<text>` | Speicherplatz schreiben, Antwort `ok` oder `err` |
| `S,0` / `S,1` | Funktionstest stoppen / starten |

Bei `W` trennt `|` die Felder, weil Name und Programmtext selbst Kommas
enthalten. Alle übrigen Befehle bleiben kommagetrennt. Ein ungültiges
Programm wird abgewiesen und **nicht** geschrieben; die Fehlermeldung nennt
den Schritt.

### Roboter → App

Eine JSON-Zeile je Telemetrieintervall:

```json
{"p":1,"m":2,"a":1,"sL":0.82,"sR":0.11,"e":-0.71,
 "dL":512,"dR":430,"dMax":613,"calOk":1,"hz":2840,
 "pr":1,"pc":7,"pn":18,"pass":1,"slot":0}
```

| Feld | Bedeutung |
|---|---|
| `p` | Phase: 0 gesperrt, 1 fährt, 2 sucht Linie, 3 Linie verloren, 4 kalibriert, 5 Akku leer, 6 wartet auf Befehl, 7 Programm beendet |
| `m` | Betriebsart (0 manuell, 1 Linienfolger, 2 Fahrprogramm) |
| `a` | freigegeben |
| `sL`, `sR` | „Linienanteil" je Sensor, 0 … 1 |
| `e` | Regelfehler, > 0 = Linie liegt rechts |
| `dL`, `dR`, `dMax` | PWM-Duty und zulässiges Maximum |
| `calOk` | Kalibrierung gültig |
| `hz` | Schleifenfrequenz — guter Gesundheitswert |
| `pr` | Fahrprogramm läuft |
| `pc`, `pn` | aktueller Schritt und Gesamtzahl — daraus die grüne Markierung in der Liste |
| `pass` | abgeschlossene Durchläufe |
| `slot` | aktiver Speicherplatz |
| `ts` | Funktionstest laeuft |
| `tp`, `tv` | Abschnitt des Funktionstests (0..7) und, bei den Motorabschnitten, die aktuelle Rampenstellung in Prozent |
| `vb` | Akkuspannung, nur mit `FEATURE_BATTERY_MONITOR` |

### Antworten außer der Telemetrie

| Typ | Wann | Inhalt |
|---|---|---|
| `cfg` | beim Verbindungsaufbau | Tuningwerte, damit die Schieberegler sofort richtig stehen |
| `slots` | beim Verbindungsaufbau und nach jedem Speichern | `a` aktiver Platz, `max` Schrittgrenze, `n[]` Namen, `c[]` belegte Schritte je Platz |
| `prog` | als Antwort auf `L` | `slot`, `name`, `p` = Programmtext |
| `ok` / `err` | nach `W` | Klartextmeldung für die Statuszeile des Editors |

---

## 4 · Fertige Apps als Rückfallebene

Falls du den WLAN-Weg doch nicht willst — etwa weil du im Betrieb im Heim-WLAN
bleiben möchtest — sind das die beiden brauchbaren Store-Apps. Beide setzen
**BLE** voraus, also einen Umbau der Firmware von WLAN auf BLE-UART
(`NimBLE-Arduino`, Nordic-UART-Service). Das Protokoll aus Abschnitt 3 kann
dabei unverändert bleiben.

| App | iOS | Android | Eignung |
|---|---|---|---|
| **Dabble** (STEMpedia) | ab iOS 11 | ja | Gamepad-Modul mit **analogem Joystick**, dazu Terminal und Regler. Nächstes Äquivalent zur gebauten Oberfläche. Es gibt eine passende Arduino-Bibliothek `DabbleESP32`, die den BLE-Teil übernimmt. **Wichtig:** die iOS-Version unterstützt ausschließlich BLE |
| **Bluefruit Connect** (Adafruit) | ab iOS 15 | ab Android 4.4 | „Controller"-Modus mit 8-Tasten-Gamepad (digital, kein analoger Joystick) plus Beschleunigungssensor. Dazu ein UART-Terminal, mit dem sich das Protokoll von Hand testen lässt — dafür auch unabhängig vom Steuerweg nützlich |

Für die reine Entwicklungsarbeit lohnt **nRF Connect** (Nordic, iOS und Android):
damit siehst du rohe BLE-Dienste und -Charakteristiken und kannst Pakete
von Hand schicken.

Einschränkung von Dabble und Bluefruit gegenüber der eigenen Web-App: Beide
bieten kein frei gestaltbares Telemetrie-Display. Die Sensorbalken und die
Live-Schieberegler für Kp/Kd müsstest du aufgeben oder in Textzeilen im
Terminal nachbilden.

---

## Quellen

- [Dabble – Bluetooth Controller im App Store](https://apps.apple.com/gb/app/dabble-bluetooth-controller/id1472734455)
- [STEMpedia/DabbleESP32 (Arduino-Bibliothek, BLE)](https://github.com/STEMpedia/DabbleESP32)
- [Dabble – Erste Schritte (STEMpedia-Doku, iOS nur BLE)](https://ai.thestempedia.com/docs/dabble-app/getting-started-with-dabble/)
- [Bluefruit Connect im App Store](https://apps.apple.com/us/app/bluefruit-connect/id830125974)
- [Adafruit Learn: Bluefruit LE Connect – Controller-Modus](https://learn.adafruit.com/introducing-the-adafruit-bluefruit-le-uart-friend/controller)

---

## 5 · Nachtrag: Sensorbefehle und Telemetriefelder

### App → Roboter

| Befehl | Bedeutung |
|---|---|
| `G` | Lagesensor nullen (Roboter dabei ruhig halten) |
| `O,<0\|1>,<mm>` | Hindernis-Stopp aus/ein und Auslöseabstand |

### Roboter → App, zusätzliche Felder

| Feld | Bedeutung |
|---|---|
| `imu` | Lagesensor gefunden |
| `hd` | Kurswinkel in Grad, relativ |
| `ic` | Nullpunkt aufgenommen |
| `dsp` | Abstandssensor gefunden |
| `ds` | Abstand in mm, 0 = nichts im Messbereich |
| `og`, `om` | Hindernis-Stopp aktiv und dessen Abstand |
| `ti` | Zusatzwert des Funktionstests: Grad bei den Drehabschnitten, mm beim Abstandsabschnitt |
| `tg`, `td` | Urteil über Lage- und Abstandssensor: 0 ungeprüft, 1 in Ordnung, 2 keine Reaktion, 3 Drehrichtung vertauscht, 4 meldet sich nicht, 5 nichts im Messbereich |

Die Phasen (`p`) sind um **9 umgekippt oder hochgehoben** und
**10 Hindernis voraus** erweitert, die Funktionstest-Abschnitte (`tp`) um
**8 Drehung rechts**, **9 Drehung links** und **10 Abstandssensor**.

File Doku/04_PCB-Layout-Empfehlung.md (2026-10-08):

# PCB-Layout-Empfehlung

Für Variante A: DevKit gesteckt, 2-lagig, **1,0 mm FR4**, Außenmaß **50 × 38 mm**.

> **Dies ist der Entwurfstext von vorher.** Die Platine ist inzwischen gebaut
> und an einigen Stellen anders ausgefallen als hier empfohlen — vor allem
> ist sie mit **70 × 52 mm** größer geworden, weil die Fertigmodule als
> senkrechte Finnen danebenstehen. Die Zahlen, die wirklich bestellt werden,
> stehen in [Fertigung/README.md](../Fertigung/README.md). Wie sie geworden
> ist, zeigt [Abschnitt 7](#7--so-ist-sie-geworden) am Ende.

---

## 1 · Fertigungsparameter

| Parameter | Wert | Begründung |
|---|---|---|
| Lagen | 2 | Alles Nötige passt; 4 Lagen wären reine Kostensteigerung |
| Dicke | **1,0 mm** | Spart 2,2 g gegenüber 1,6 mm, bei JLCPCB zum gleichen Preis |
| Kupfer | 35 µm (1 oz) | Reicht für 1,1 A Spitzenstrom bei den unten genannten Bahnbreiten |
| Leiterbahn minimal | 0,25 mm | Weit über der Billigfertigungsgrenze, kein Aufpreis |
| Bohrung minimal | 0,3 mm | dito |
| Oberfläche | HASL bleifrei | ENIG lohnt sich hier nicht |
| Außenmaß | 50 × 38 mm | Breite durch die 25,4 mm Buchsenabstand des DevKits plus Rand bestimmt |

Bei JLCPCB kosten 5 Stück in dieser Spezifikation etwa 7 € plus Versand.

---

## 2 · Bahnbreiten und Masseführung

| Netz | Breite | Hinweis |
|---|---|---|
| VBAT (Akku → Schalter → U5) | **0,8 mm** | Spitzenstrom bis 1,1 A |
| +5 V (U5 → VIN) | **0,8 mm** | dito |
| Motorzweige (+5 V → Motor → Drain) | **0,5 mm** | ≈ 100 mA, aber impulsförmig |
| GND-Rückleitung der Motoren | **0,8 mm** | der kritischste Pfad, siehe unten |
| Signale (PWM, ADC, LEDs) | 0,25 mm | |

### Die wichtigste Layoutregel dieses Projekts

**Der Rückstrom der Motoren darf nicht durch die Massefläche laufen, die der
ADC als Bezug benutzt.** Sonst moduliert jeder Motorimpuls den Sensorwert und
der PD-Regler reagiert auf sein eigenes Rauschen.

Praktisch heißt das: **Sternpunkt-Masse.** Von einem Massepunkt direkt am
Minuspol des Akkus (bzw. am GND-Anschluss von U5) gehen drei getrennte Pfade ab:

```
            GND-Sternpunkt (am Akku-Minus / U5-GND)
             |            |              |
     Emitter Q1+Q2    DevKit GND     R7, R8, OS1, OS2 GND
     (Motorrückstrom) (Logik)        (Sensormasse)
```

Die Emitter von Q1 und Q2 bekommen eine eigene, breite Bahn zum Sternpunkt —
nicht über die allgemeine Massefläche und **nicht** über denselben Weg, den R7
und R8 benutzen. Auf der Unterseite eine durchgehende Massefläche vorsehen, aber
die Motorrückleitung als eigene Bahn darauf führen.

### Entkopplung

* **C3, C4 (100 nF)** so dicht wie möglich an den Drains von Q1 und Q2,
  Rückweg direkt zur Source desselben MOSFETs — nicht quer über das Board.
* **C1 (100 µF Elko) + C2 (10 µF Keramik)** an der 5-V-Schiene, zwischen U5 und
  der Abzweigung zu den Motoren. Also dort, wo der Puls entsteht, nicht am
  DevKit.
* **D1, D2 (Freilauf)** direkt an den Motorklemmen, Schleife so klein wie
  möglich. Eine lange Schleife strahlt die Abschaltspitze ab.

---

## 3 · Platzierung

```
                            V O R N
     ┌───────────────────────────────────────────────┐
     │  LED1◦      [OS1]      [OS2]       ◦LED2      │
     │  gelb                               gelb      │
     │  ┌──M1──┐                       ┌──M2──┐      │
     │  │Motor │  Q1 D1   C1 C2  D2 Q2 │Motor │      │
     │  └──────┘                       └──────┘      │
     │        ┌───────────────────────────┐          │
     │        │                           │          │
   ╔═╪════════╡      ESP32 DevKit V1      ╞══════════╪═╗  ← Antenne ragt
   ║ │        │   (auf Buchsenleisten)    │          │ ║    über die Kante
     │        │   darunter: LiPo 500 mAh  │          │
     │        └───────────────────────────┘          │
     │                                               │
     │   [U5 MT3608]   S1   [TP4056 + USB-C ▸]       │
     │  LED3◦                             ◦LED4      │
     │   rot                               rot       │
     └───────────────────────────────────────────────┘
                           H I N T E N
```

### Begründungen

**Antennenende über die Platinenkante.** Unter dem Antennenbereich des
DevKit-Moduls darf **kein Kupfer** liegen — keine Bahn, keine Massefläche, kein
Bauteil. Das kostet sonst Reichweite und erzeugt Verbindungsabbrüche. Das DevKit
so stecken, dass die Antenne frei über die Kante hinausschaut; im Layout dort
eine Sperrfläche (Keepout) definieren.

**Motoren weit außen und weit vorn.** Das Lenkmoment ist das Produkt aus
Vibrationskraft und Abstand zur Längsachse. Jeder Millimeter weiter außen zahlt
sich direkt in Lenkautorität aus. Weit vorn bringt zusätzlich, dass die
Vorderachse leichter ausbricht — genau das, was Lenken bei einem
Vibrationsantrieb bedeutet.

**Sensoren vorn zwischen den Motoren.** Mittenabstand OS1 ↔ OS2 passend zur
Linienbreite: bei einem 19-mm-Isolierband **15–20 mm**. Dann sieht jeder Sensor
in der Geradeausfahrt je eine Kante der Linie etwa halb verdeckt — der Punkt
mit der größten Steigung und damit der besten Regelempfindlichkeit.

**Sensorhöhe 2–5 mm über dem Boden.** Der TCRT5000 hat sein Optimum bei etwa
2,5 mm. Darüber sinkt das Signal schnell. Die Sensoren deshalb mit abgewinkelten
Beinen nach unten setzen oder die Platine entsprechend hoch lagern — und auf
gleiche Höhe beider Sensoren achten, sonst ist der Nullpunkt schief (die
Kalibrierung fängt das zwar auf, aber auf Kosten des Hubs).

**Akku mittig unter dem DevKit.** Er ist mit 10 g das schwerste Einzelteil.
Mittig heißt: Schwerpunkt auf der Längsachse, keine Schlagseite. Mit
Schaumklebeband befestigen, das entkoppelt gleichzeitig die Vibration.

**USB-C und Schalter nach hinten.** Dort kommt man beim Laden dran, ohne die
Sensorik anzufassen.

---

## 4 · Mechanik

* **Zwei getrennte Borstenfelder**, je eines unmittelbar unter M1 und M2. Auf
  einer gemeinsamen Grundplatte verteilt sich die Vibration und die Differenz
  zwischen den Motoren mittelt sich weg — der Roboter lenkt dann kaum. Das ist
  die wichtigste mechanische Entscheidung am ganzen Aufbau.
* **Borsten schräg nach hinten** anstellen (ca. 15–25° aus der Senkrechten).
  Die Vorzugsrichtung entsteht genau daraus; senkrechte Borsten vibrieren auf
  der Stelle.
* **Montagelöcher:** 4× Ø 2,2 mm für M2-Schrauben, 3 mm von den Ecken. Dienen
  gleichzeitig als Befestigung für die Borstenträger.
* **Keine Verschraubung direkt zwischen Motor und Platine.** Den Motor mit
  Schaumklebeband aufsetzen: starre Verschraubung überträgt die Vibration ins
  ganze Board (und in den Elko und die Lötstellen) statt in die Borsten.

---

## 5 · Checkliste vor der Bestellung

- [ ] Platinendicke auf **1,0 mm** gesetzt
- [ ] Keepout unter dem Antennenbereich des DevKits, kein Kupfer
- [ ] DevKit-Buchsenleisten im Raster 2,54 mm, Abstand **25,4 mm** (30-Pin-Version!)
- [ ] GND-Sternpunkt eingezeichnet, Motorrückstrom als eigene Bahn
- [ ] C3/C4 unmittelbar an Q1/Q2, Freilaufdioden an den Motorklemmen
- [ ] R13/R14 (2× 5,1 kΩ) an CC1/CC2 vorhanden — sonst lädt nichts
- [ ] R_prog = 4,7 kΩ, nicht 1,2 kΩ
- [ ] Polung der JST-PH-Buchse gegen den tatsächlich gekauften Akku geprüft
- [ ] Sensorabstand zur Linienbreite passend (15–20 mm bei 19-mm-Band)
- [ ] Beschriftung im Siebdruck: Polung des Akkus, Soll-Ausgangsspannung von U5
      („**U5 = 5V0**") direkt neben der Lötaugenreihe von U5. Der Trimmer ist
      dort nicht mehr — U5 wird vor dem Einbau auf einen Festteiler 110 k/15 k
      umgebaut, siehe [Inbetriebnahme Schritt 1a](07_Inbetriebnahme-und-Tuning.md)

---

## 6 · Nachtrag: die beiden Sensoren

### MPU-6050 (Lage) — aufs Chassis, nicht auf den Mast

Drei Regeln, und alle drei sind auf diesem Roboter nicht optional:

1. **Nahe der Drehachse.** Der Sensor misst die Drehrate um die Hochachse.
   Sitzt er weit außen, überlagert die Zentrifugalbeschleunigung die
   Lagemessung. Platz: mittig, möglichst dicht am Schwerpunkt.
2. **Weit weg von den Motoren.** Nicht wegen des Magnetfelds — das stört ein
   Gyro kaum — sondern wegen der mechanischen Anregung. Jeder Zentimeter
   Abstand hilft.
3. **Weich ankoppeln.** Mit demselben Schaumklebeband aufsetzen wie den
   Akku. Starr verschraubt bekommt der Sensor die volle Motorvibration ab,
   und die ist auf diesem Gerät das größte Messproblem überhaupt.
   Stiftleisten abknipsen und flach verlöten — ein gestecktes Modul wackelt
   im Sockel, und genau dieses Wackeln misst der Sensor dann.

### VL53L0X (Abstand) — auf den Mast

| | |
|---|---|
| Masthöhe | ca. 60 mm über der Platine |
| Position | vorn mittig, zwischen den beiden Liniensensoren |
| Blickrichtung | **waagerecht nach vorn** |
| Werkstoff | CFK-Rundstab Ø 3 mm — steif und mit 0,6 g fast masselos |

**Warum der Mast hier funktioniert, ein Magnetometer dort aber nicht:** Eine
optische Laufzeitmessung mittelt über ihr Messfenster von 33 ms. Ein
peitschender Mast verwischt dabei höchstens den Zielpunkt, nicht den
Messwert. Ein Magnetometer dagegen würde oben zwar weniger Motorfeld sehen,
dafür aber in der Mastbewegung seine Ausrichtung verlieren — und die
Ausrichtung ist bei einem Kompass die Messgröße.

**Nicht nach unten neigen.** Ein zum Boden geneigter Sensor misst die
Tischplatte und meldet dauernd „Hindernis". Waagerecht, und beim ersten
Aufbau mit der Live-Anzeige in der Oberfläche prüfen: freie Strecke muss
„frei" anzeigen, nicht einen Wert um 100 mm.

**Kabel verdrillt am Mast entlang, am Fuß eine Schlaufe lassen.** Ein straff
gespanntes Kabel bricht an einem vibrierenden Mast genau an der Lötstelle.

### Massefolgen fürs Layout

Die 4,5 g der Sensorik sitzen zu etwa der Hälfte oben. Das verschiebt den
Schwerpunkt nach vorn und nach oben. Zwei Gegenmaßnahmen, beide kostenlos:

* Akku so weit **nach hinten** setzen, wie das Layout zulässt
* PCB in **1,0 mm** statt 1,6 mm bestellen (siehe Checkliste oben) —
  das allein holt die Mastmasse mehr als zurück

---

## 7 · So ist sie geworden

Drei Ansichten der fertig gerouteten Platine. Sie kommen aus KiCad selbst
(`kicad-cli pcb render`), zeigen also exakt die Daten, die auch in die
Gerber gehen — kein nachgezeichnetes Schaubild. Neu erzeugt werden sie von
[`Fertigung/erzeuge_fertigungsdaten.sh`](../Fertigung/erzeuge_fertigungsdaten.sh).

### Gesamtansicht

Schrägansicht der bestückten Platine

**Wozu dieses Bild dient:** der schnelle Eindruck, wie hoch das Ganze baut.
Gut zu sehen ist, dass das DevKit die halbe Fläche überdeckt und auf
Buchsenleisten gut 8,5 mm darüber schwebt — darunter liegt bewusst alles
Flache. Für den Entwurf des 3D-Basismoduls ist das die Ansicht, an der man
die Bauhöhe abschätzt; die genauen Maße liefert
[`Fertigung/MarsRover-platine.step`](../Fertigung/MarsRover-platine.step).

### Oberseite

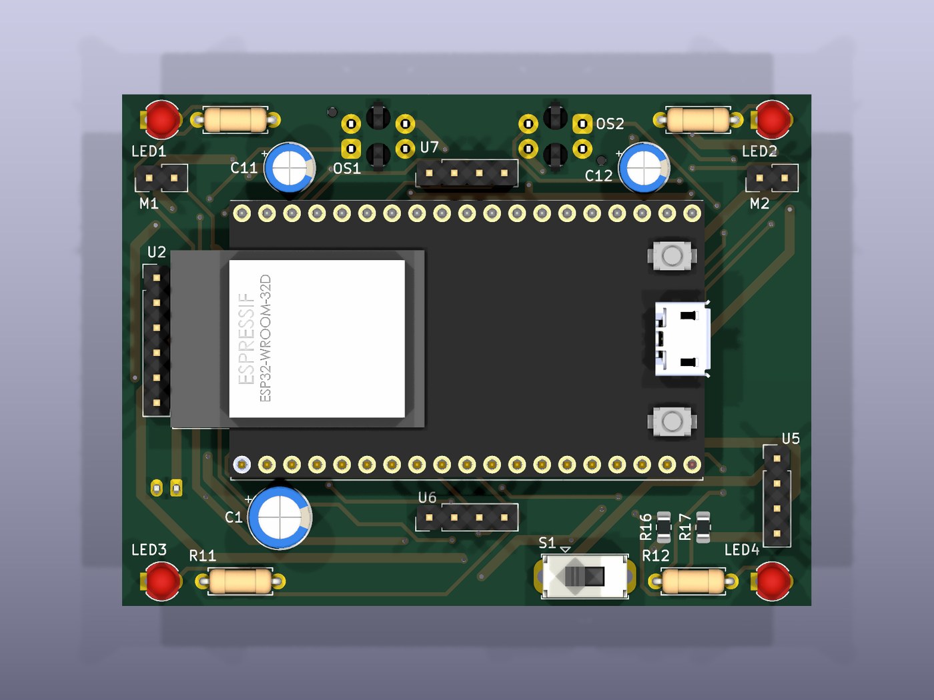
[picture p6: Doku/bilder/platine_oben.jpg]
Draufsicht auf die Oberseite


**Wozu dieses Bild dient:** die Bestückungsübersicht. Hier sieht man die
Aufteilung in drei Streifen — **vorn** die Motoranschlüsse M1/M2, die
Pufferelkos C11/C12 und der Abstandssensor U7; **in der Mitte** das DevKit
quer mit den beiden Finnen U2 (Laderegler) und U5 (Step-Up) links und
rechts; **hinten** Ladebuchse, Schalter S1, der Lagesensor U6 mittig und
die roten LEDs.

Rechts am DevKit ist der **Micro-USB** frei zugänglich — U5 stand dort
ursprünglich davor und musste dafür an die Hinterkante wandern.

### Unterseite

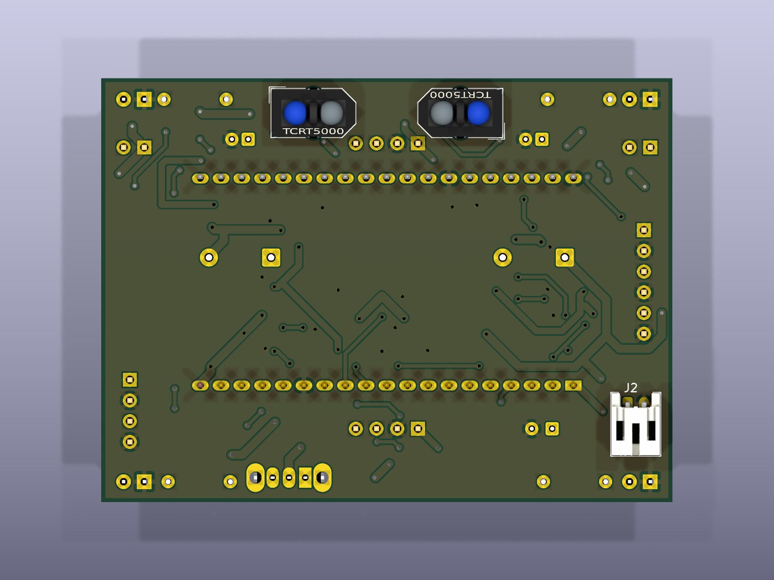
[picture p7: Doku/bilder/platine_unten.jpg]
Ansicht der Unterseite


**Wozu dieses Bild dient:** die Unterseite ist die Seite, die den Boden
sieht, und sie trägt die Teile, auf die es beim Linienfolgen ankommt. Die
beiden **TCRT5000** stehen hier gegeneinander um 180° gedreht, so dass die
Fototransistoren nach innen zeigen; ihre optischen Messflecken liegen damit
18 mm auseinander, passend zu einem 19-mm-Band. Rechts hinten sitzt der
**liegende Akkustecker**, damit das Kabel parallel zur Platine herauskommt
und nicht in den Spalt zum darunterliegenden Akku ragt.

Die olivfarbene Fläche über die ganze Platine ist die **Massefläche**. Rund
um jedes bedrahtete Masse-Pad erkennt man den schmalen Ring der
Wärmefalle — vier Stege statt voller Anbindung, damit die Fläche beim
Handlöten die Wärme nicht schneller abzieht, als der Kolben sie nachliefert.

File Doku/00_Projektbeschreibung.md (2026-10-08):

# One-of-a-Kind Mars Rover

Ein fahrender, programmierbarer Roboter, der sich **durch Vibration**
fortbewegt. Kein Rad, kein Getriebe, keine Achse: zwei kleine
Unwuchtmotoren rütteln zwei Zahnbürstenköpfe, und weil deren Borsten
schräg stehen, stützen sie sich in eine Richtung leichter ab als in die
andere. Daraus entsteht Vortrieb.

Gesteuert wird er vom Handy aus über ein eigenes WLAN, das der Roboter
selbst aufspannt — ohne App, ohne Heimnetz, auf iPhone und Android gleich.
Er kann einer Linie folgen, sich von Hand per Joystick fahren lassen oder
**ein selbst zusammengestelltes Fahrprogramm abspielen**.

> **Zum Namen.** Das Projekt heißt *One-of-a-Kind Mars Rover* — jedes
> gebaute Exemplar bekommt einen eigenen Namen und ein eigenes WLAN
> (`MarsRover_Petra`), damit mehrere gleichzeitig nebeneinander fahren
> können. In der gesamten Dokumentation heißt der Roboter deshalb
> durchgehend **Mars Rover**.

> **Verwandt mit dem Bristlebot.** Vielleicht kennst du den *Bristlebot*:
> jenen kleinen Vibrationsläufer aus einem Zahnbürstenkopf, einem
> Unwuchtmotor und einer Knopfzelle, der über den Tisch summt. Der Mars
> Rover fährt nach genau demselben Prinzip — nur kann er deutlich mehr:
>
> | Bristlebot | Mars Rover |
> |---|---|
> | ein Motor | **zwei** Motoren, und erst dadurch kann er lenken |
> | fährt, wohin ihn der Zufall trägt | **folgt einer Linie** und sieht, wo sie liegt |
> | keine Elektronik | ESP32 mit Lageerkennung und Abstandsmessung |
> | an/aus | **vom Handy steuerbar**, mit selbst zusammengestellten Fahrprogrammen |
>
> Kurz gesagt: ein Bristlebot fährt, wohin er will — dieser hier fährt,
> wohin du willst.

---

## 1 · Was ihn ausmacht

**Er hat keine Räder.** Das ist kein Mangel, sondern das Prinzip. Ein
Vibrationsantrieb hat keine beweglichen Teile außer dem Motor selbst, keine
Lager, keine Zahnräder, nichts, was sich verhaken kann. Er ist damit
mechanisch beinahe unzerstörbar — und zugleich schwer vorhersehbar, weil
der Vortrieb von Untergrund, Borstenstellung, Gewicht und Akkustand abhängt.

Genau das macht ihn interessant: **man muss ihn kennenlernen.** Ein
Roboter mit Rädern fährt 20 cm, wenn man ihm sagt, er solle 20 cm fahren.
Dieser hier fährt „zwei Sekunden lang", und wie weit das ist, findet man
durch Ausprobieren heraus. Für den Einstieg ins Programmieren ist das ein
Vorteil, kein Nachteil — Rückmeldung aus der echten Welt statt aus einer
Simulation.

**Er lenkt durch Ungleichheit.** Zwei Motoren, zwei getrennte
Borstenfelder. Vibriert links stärker als rechts, dreht er nach rechts. Es
gibt keinen Lenkmechanismus, nur zwei Zahlen.

---

## 2 · Aufbau

| Baugruppe | Was sie tut |
|---|---|
| **ESP32** | Rechner, WLAN-Zugangspunkt und Webserver in einem Modul |
| **2 Vibrationsmotoren** | Antrieb, über Transistoren geschaltet, in 1024 Stufen regelbar |
| **2 Zahnbürstenköpfe** | je einer unter einem Motor — getrennt, sonst mittelt sich die Lenkung weg |
| **2 Reflexkoppler** | schauen nach unten und erkennen die Linie |
| **Lagesensor** | misst Drehungen, damit „drehe um 90°" wirklich 90° sind |
| **Abstandssensor** | sitzt auf einem Mast und schaut nach vorn |
| **4 LEDs** | zwei gelbe vorn als Blinker, zwei rote hinten als Rücklicht |
| **LiPo-Akku + Ladeelektronik** | Laden über USB-C, Laufzeit rund eine Stunde |

Die Sensorik ist **vollständig optional**. Fehlt der Lagesensor, laufen
Drehbefehle zeitgesteuert statt geregelt. Fehlt der Abstandssensor,
beenden sich die Hindernisbefehle nach ihrer Zeitgrenze. Der Roboter sagt
in der Bedienoberfläche selbst, was er hat und was nicht. Man kann also
klein anfangen und später nachrüsten.

---

## 3 · Die Bedienoberfläche

Der Roboter **bringt seine eigene Bedienoberfläche mit**. Sie liegt im
Speicher des ESP32 und wird von ihm ausgeliefert, sobald man sich mit
seinem WLAN verbindet. Kein App-Store, keine Installation, kein Konto.

```
Einschalten  →  am Handy ins WLAN "MarsRover_…"  →  Seite öffnet sich
```

Auf dem iPhone klappt das Bedienfenster meist von selbst auf; sonst
`http://192.168.4.1` im Browser aufrufen.

Die Oberfläche ist auf Bedienbarkeit **ab 14 Jahren** ausgelegt: Klartext
statt Kürzel, große Tippflächen, Farbcodierung, und alles, was man zum
Fahren nicht braucht, liegt hinter einem zugeklappten Experten-Bereich.

### Was man sieht

| Bereich | Inhalt |
|---|---|
| **Freigeben** | Nach dem Einschalten ist der Roboter gesperrt. Ohne Freigabe läuft kein Motor |
| **Betriebsart** | Linie folgen · Selbst fahren · Fahrprogramm |
| **Messwerte** | Sensoren, Motoren, Kurs und Abstand — live |
| **Funktionstest** | prüft alles der Reihe nach durch |
| **Experten** | Reglerabstimmung, Kalibrierung, eigener Name |
| **NOTHALT** | hält alles an und entzieht die Freigabe |

---

## 4 · Die drei Betriebsarten

### Linie folgen

Zwei Reflexkoppler schauen nach unten, je einer links und rechts der
Linie. Sieht der linke mehr Linie als der rechte, liegt der Roboter zu
weit rechts — also stärker nach links lenken. Das erledigt ein
**PD-Regler**: der P-Anteil reagiert auf die Abweichung, der D-Anteil auf
deren Änderungsgeschwindigkeit und dämpft damit das Überschwingen.

Vor der ersten Fahrt muss **kalibriert** werden: Knopf drücken, den
Roboter fünf Sekunden quer über die Linie schwenken, fertig. Er merkt
sich, wie hell der Untergrund und wie dunkel die Linie ist. Die Werte
überleben das Ausschalten.

Verliert er die Linie, sucht er sie: erst in die Richtung, in der sie
zuletzt lag, dann pendelnd. Nach vier Sekunden gibt er auf und hält an.

### Selbst fahren

Ein Joystick auf dem Handy. Nach oben = schneller, zur Seite = lenken.
Steht er still und man schlägt voll zur Seite aus, dreht er auf der Stelle.

**Rückwärts gibt es nicht.** Ein Unwuchtmotor treibt den Roboter nur in
Borstenrichtung; die Drehrichtung des Motors ändert daran nichts. Joystick
nach unten heißt deshalb schlicht „Halt".

Ein **Totmannschalter** passt auf: kommt länger als eine halbe Sekunde
kein Befehl — Handy weggelegt, Browser im Hintergrund, WLAN abgerissen —
halten die Motoren an.

### Fahrprogramm

Der interessanteste Teil. Dazu das ganze nächste Kapitel.

---

## 5 · Programmieren

Das ist das Herzstück: Man stellt sich in der Weboberfläche einen Ablauf
zusammen, speichert ihn im Roboter und lässt ihn abspielen. Vier
Speicherplätze, je 48 Schritte, alles im Flash — es überlebt Stromausfall
und sogar ein Neuaufspielen der Firmware.

### 5.1 Der eine Gedanke, auf den es ankommt

**Jeder Befehl wirkt sofort. Zeit verbraucht nur `warte`.**

Das ist anders, als man es erwartet, und es ist der Punkt, an dem am
Anfang alle stolpern. Ein Fahrbefehl sagt nicht „fahre eine Weile
geradeaus". Er sagt: „ab jetzt geradeaus" — und ist in derselben
Tausendstelsekunde fertig. Erst `warte` lässt Zeit vergehen.

```
geradeaus mit 60 %        ← schaltet die Fahrt ein, dauert 0 Sekunden
LED vorne links blinken   ← schaltet den Blinker ein, dauert 0 Sekunden
warte 2,0 Sekunden        ← JETZT vergehen 2 Sekunden, fahrend und blinkend
```

Warum so? Weil sich damit **alles frei kombinieren lässt**. Fahren und
Blinken und Lichtwechsel laufen gleichzeitig, ohne dass die Sprache dafür
eine eigene Konstruktion bräuchte. Man schaltet Dinge ein, und dann lässt
man Zeit vergehen.

Daraus folgt die Regel, die man sich merken muss:

> **Ein Befehl ohne nachfolgendes `warte` ist unsichtbar.**

`anhalten` direkt vor `von vorn wiederholen` sieht man nie — der Ablauf
springt sofort zurück und fährt weiter. Will man eine Pause sehen, muss
nach dem Anhalten ein `warte` stehen.

**Die Ausnahmen:** Vier Befehle brauchen von sich aus Zeit, weil sie auf
einen Sensor warten — `drehen um … Grad`, `fahren bis Hindernis`,
`drehen bis frei` und `warten bis frei`. Sie sind fertig, wenn das Ziel
erreicht ist, und blockieren den Ablauf so lange.

### 5.2 Die Befehle

#### Fahren

| Befehl | Werte | Wirkung |
|---|---|---|
| **geradeaus fahren** | 1–100 % | beide Motoren gleich stark |
| **Kurve nach links** | Radius 1–10, 1–100 % | **Stufe 1 = engste Kurve**, dreht fast auf der Stelle. Stufe 10 = weiter, sanfter Bogen |
| **Kurve nach rechts** | dto. | |
| **anhalten** | — | Motoren aus |

Jeder Fahrbefehl trägt seine Geschwindigkeit selbst. Einen getrennten
Tempo-Befehl gibt es nicht: Tempowechsel heißt, den nächsten Fahrbefehl
mit einer anderen Zahl einzufügen. Das klingt umständlicher, ist beim
Lesen aber viel klarer — man sieht an jeder Zeile, wie schnell er dabei
ist.

#### Zeit

| Befehl | Werte | Wirkung |
|---|---|---|
| **warte** | 0,1–20,0 s | der einzige Befehl, der für sich genommen Zeit verbraucht |

#### Licht

| Befehl | Werte | Wirkung |
|---|---|---|
| **LED schalten** | Ziel + Zustand | Ziel: einzeln, beide vorne, beide hinten, alle vier. Zustand: ein, aus, blinken |
| **Blinkfrequenz** | Stufe 1–10 | 0,5 bis 5 mal pro Sekunde, gilt für alle blinkenden LEDs |

#### Mit Lagesensor

| Befehl | Werte | Wirkung |
|---|---|---|
| **drehen nach links/rechts um … Grad** | 5–360°, 1–100 % | dreht auf der Stelle, bis der Lagesensor den Winkel meldet |

Das ist der Unterschied zwischen *hoffen* und *wissen*. Ohne Lagesensor
müsste man schreiben „dreh 1,2 Sekunden nach rechts" und darauf
vertrauen, dass das etwa 90° werden — bei vollem Akku mehr, bei leerem
weniger. Mit Sensor dreht er, bis es 90° **sind**.

#### Mit Abstandssensor

| Befehl | Werte | Wirkung |
|---|---|---|
| **fahren bis Hindernis** | 40–1200 mm, 1–100 % | fährt geradeaus, bis etwas näher ist als der Wert |
| **drehen bis frei** | 40–1200 mm, 1–100 % | dreht, bis nach vorn wieder frei ist |
| **warten bis frei** | 40–1200 mm | steht still, bis der Weg frei ist |

#### Ablauf

| Befehl | Werte | Wirkung |
|---|---|---|
| **von vorn wiederholen** | 0–10 | **0 = endlos**, sonst so viele *weitere* Durchläufe |

Dieser Befehl darf nur als letzte Zeile stehen und nur einmal vorkommen.
Die Oberfläche sorgt selbst dafür — neue Befehle rutschen automatisch
davor.

### 5.3 Wie man vorgeht

**Erst das Ziel in Worte fassen, dann in Zeilen.** Das klingt banal, spart
aber die meiste Zeit.

Beispiel: *„Er soll ein Stück geradeaus fahren, rechts abbiegen und dabei
blinken, dann weiter, und das vier Mal."*

Daraus wird Zeile für Zeile:

```
geradeaus mit 50 %
warte 2,0 Sekunden
LED vorne rechts blinken          ← Blinker AN, bevor die Kurve beginnt
drehen nach rechts um 90°, 70 %
LED vorne rechts ausschalten
von vorn wiederholen, 3 mal
```

Sechs Zeilen für ein Quadrat. Drei Beobachtungen daran:

1. **Der Blinker steht vor der Drehung**, nicht danach — sonst blinkt er,
   wenn die Kurve schon vorbei ist.
2. **Nach der Drehung kein `warte`** — der Drehbefehl bringt seine Zeit
   selbst mit.
3. **`3 mal` ergibt vier Runden**: der erste Durchlauf plus drei
   Wiederholungen. Das ist genau ein Quadrat.

### 5.4 Vom Einfachen zum Schwierigen

#### Stufe 1 — nur Licht

```
Blinkfrequenz Stufe 8
alle vier LEDs blinken
warte 3,0 Sekunden
alle vier LEDs ausschalten
warte 1,0 Sekunden
von vorn wiederholen, endlos
```

Kein Fahrbefehl. Ideal zum Begreifen des Zeitmodells, weil man jeden
Schritt direkt sieht und nichts wegrollt.

#### Stufe 2 — geradeaus und zurück zum Stillstand

```
geradeaus mit 45 %
warte 1,5 Sekunden
anhalten
warte 1,0 Sekunden
von vorn wiederholen, endlos
```

Hier lernt man die Regel aus 5.1: Lässt man das letzte `warte` weg, sieht
man vom Anhalten nichts.

#### Stufe 3 — die Acht

```
beide LEDs hinten einschalten
geradeaus mit 55 %
warte 1,5 Sekunden
Kurve rechts, Stufe 4, 55 %
LED vorne rechts blinken
warte 2,5 Sekunden
LED vorne rechts ausschalten
Kurve links, Stufe 4, 55 %
LED vorne links blinken
warte 2,5 Sekunden
LED vorne links ausschalten
geradeaus mit 55 %
warte 1,5 Sekunden
anhalten
alle vier LEDs ausschalten
warte 1,0 Sekunden
von vorn wiederholen, endlos
```

Dieses Programm liegt beim ersten Einschalten schon auf Platz 1. Es ist
zum Auseinandernehmen gedacht: Geschwindigkeiten ändern, Radien ändern,
Wartezeiten ändern und zusehen, was passiert.

#### Stufe 4 — selbsttätig ausweichen

```
fahren bis Hindernis in 120 mm, 60 %
drehen nach rechts, bis 300 mm frei, 70 %
warte 0,3 Sekunden
von vorn wiederholen, endlos
```

Vier Zeilen, und er fährt selbständig durch einen Raum. Das kurze `warte`
gibt dem Abstandssensor nach der Drehung einen Moment, bevor die nächste
Anfahrt beginnt.

Das ist der Punkt, an dem aus einem Ablauf ein **Verhalten** wird: Das
Programm beschreibt nicht mehr eine Strecke, sondern eine Regel — *fahr,
bis etwas im Weg ist; dreh dich weg; von vorn*. Was dabei herauskommt,
hängt vom Raum ab, nicht vom Programm.

### 5.5 Was typischerweise schiefgeht

| Beobachtung | Ursache |
|---|---|
| Programm ist sofort durch, man sieht nichts | `warte` vergessen |
| Er fährt, aber die Lichter bleiben aus | LED-Befehl steht **nach** dem `warte` statt davor |
| Die letzte Aktion ist nie zu sehen | kein `warte` vor `wiederholen` |
| Die Drehung wird zu klein | Geschwindigkeit zu niedrig — eine Drehung auf der Stelle braucht mehr Vibration als Geradeausfahrt |
| Er dreht in die falsche Richtung | Lagesensor um 180° verdreht montiert. Der **Funktionstest** erkennt das und sagt es |
| Beim Speichern eine Fehlermeldung | Werte außerhalb des erlaubten Bereichs. Die Meldung nennt die Zeilennummer, und **nichts wird gespeichert** — das kaputte Programm landet nie im Roboter |

### 5.6 Die Grenze: er kann keine Strecken

Der Roboter weiß, **wie weit er sich gedreht** hat. Er weiß nicht, **wie
weit er gefahren** ist. Es gibt keine Radgeber, und die Beschleunigung
zweimal aufzuintegrieren ist bei einem Gerät, dessen Antriebsprinzip
Schütteln ist, nach ein bis zwei Sekunden wertlos.

**„Fahre 30 cm" gibt es also nicht.** Als Ersatz dienen zwei Dinge:

* `fahren bis Hindernis` — keine Strecke, aber ein definierter Endpunkt
* der **Linienfolger** — die Linie auf dem Boden ist die Wegmessung

Ein Quadrat, das nach vier Runden wieder exakt am Start steht, wird dieser
Roboter nicht fahren. Die Drehungen stimmen, die Strecken streuen.

### 5.7 Für alle, die tiefer wollen

Das Programm liegt im Roboter als kompakte Zeichenkette, zum Beispiel:

```
ld,5,1;ge,55;wa,1500;re,4,55;ld,1,2;wa,2500;…;lo,0
```

Man muss das nicht kennen — die Oberfläche zeigt immer Klartext. Aber es
ist dokumentiert ([08_Fahrprogramm.md](08_Fahrprogramm.md)), samt dem
WebSocket-Protokoll ([06](06_Fernsteuerung-App.md)). Wer eine eigene
Steuerung, ein Skript oder eine Fernbedienung mit echten Knöpfen bauen
will, hat alles, was er dazu braucht.

Und wer noch tiefer will: Der Interpreter steckt in `Program.cpp` und ist
rund 200 Zeilen lang. Er ist bewusst so geschrieben, dass man ihn lesen
kann.

---

## 6 · Weitere Funktionen

### Funktionstest

Ein eingebauter Selbsttest, der alles der Reihe nach durchläuft: die vier
LEDs einzeln, dann alle blinkend, dann Motor links von langsam auf
schnell, dann Motor rechts. Zum Schluss dreht er sich einmal nach rechts
und einmal nach links und prüft dabei den Lagesensor, und er zeigt den
Messwert des Abstandssensors.

Der Teil mit den beiden Drehungen ist der wertvollste: Er prüft nicht nur,
**ob** der Lagesensor antwortet, sondern auch, **in welche Richtung er
zählt**. Ein um 180° verdreht montierter Sensor würde sonst erst beim
ersten Fahrprogramm auffallen — und dort sieht es aus wie ein
Programmierfehler, nicht wie ein Montagefehler.

Beim Motortest leuchtet jeweils die LED der getesteten Seite. Vibriert der
rechte Motor, während links die LED leuchtet, sind die Anschlüsse
vertauscht.

### Schutzfunktionen

| Funktion | Was sie tut |
|---|---|
| **Freigabe** | Nach dem Einschalten ist alles gesperrt. Er fährt nicht von selbst vom Tisch |
| **Totmannschalter** | Im Handbetrieb: kein Befehl für 0,5 s → Motoren aus |
| **Kippschutz** | Liegt er auf der Seite oder wird er hochgehoben, gehen die Motoren aus |
| **Hindernis-Stopp** | Kommt er etwas zu nahe, hält er an. Abschaltbar |
| **NOTHALT** | Ein großer roter Knopf, immer sichtbar |

### Eigener Name

Jeder Rover bekommt einen eigenen Netznamen. Ab Werk hängt die Firmware
eine aus der Seriennummer des Chips abgeleitete Kennung an —
`MarsRover_A3F2` — damit mehrere Geräte nebeneinander funktionieren, ohne
dass jemand etwas einstellen muss.

Wer will, trägt im Experten-Bereich einen eigenen Namen ein. Dann heißt
der Zugangspunkt `MarsRover_Petra`. Der Name wird gespeichert und ist nach
einem Neustart aktiv, den die Oberfläche gleich mit auslöst.

---

## 7 · Technische Daten

| | |
|---|---|
| Rechner | ESP32, 240 MHz, WLAN-Zugangspunkt |
| Antrieb | 2 Vibrationsmotoren, 20 kHz PWM, 1024 Stufen |
| Liniensensorik | 2× TCRT5000, analog, 12 bit |
| Lagesensor | MPU-6050 (optional) |
| Abstandssensor | VL53L0X, 40–1200 mm (optional) |
| Anzeige | 4 LEDs |
| Energie | LiPo 500 mAh, Laden über USB-C |
| Laufzeit | ≈ 1,2 h fahrend, ≈ 2 h im Stand |
| Masse | ≈ 45 g |
| Fahrprogramme | 4 Speicherplätze, je 48 Schritte |
| Bedienung | Browser, iPhone und Android, keine App |
| Materialkosten | ≈ 34 € |

---

## 8 · Was noch kommt

### Bauanleitung mit Bildern

Eine Schritt-für-Schritt-Anleitung vom nackten Bauteil bis zum fahrenden
Roboter, bebildert. Noch nicht geschrieben — sie entsteht beim Bau des
ersten Exemplars, weil eine Anleitung nur dann etwas taugt, wenn sie
jemand beim tatsächlichen Zusammenbauen mitgeschrieben hat.

### 3D-gedrucktes Basismodul

Das Chassis soll gedruckt werden und drei Aufgaben erfüllen:

1. **Die Platine tragen** — mit definierten Befestigungspunkten
2. **Die Zahnbürstenköpfe aufnehmen** — zum Aufrasten, werkzeuglos
   wechselbar, weil die Borsten das Verschleißteil sind
3. **Die Vibrationsmotoren halten** — in definierter Lage, elastisch
   angekoppelt

Das ist **nicht** einfach ein Gehäuse. Am Basismodul hängen die
Eigenschaften, die über Fahren oder Nichtfahren entscheiden:

| Anforderung | Warum |
|---|---|
| Zwei **getrennte** Borstenaufnahmen | Auf einer gemeinsamen Fläche mittelt sich die Vibrationsdifferenz weg und er lenkt nicht mehr |
| Motoren möglichst weit **außen und vorn** | Der Lenkhebel wächst linear mit dem Abstand zur Längsachse |
| Motoren **elastisch** angekoppelt | Starr verschraubt geht die Vibration ins Board statt in die Borsten |
| So **leicht** wie möglich | Masse ist bei diesem Antrieb die Funktionsgrenze, nicht der Komfort |
| Sensoren vorn, definierte **Bodenfreiheit** | Die Reflexkoppler arbeiten bei 2–3 mm optimal |
| Aufnahme für den **Mast** | Abstandssensor, waagerecht nach vorn |
| Akku **mittig und tief** | Schwerpunkt auf der Längsachse, nicht kippelig |

**Platine und Basismodul müssen zusammen entworfen werden** — das eine
legt die Befestigungspunkte, Bauteilhöhen und Sensorpositionen des anderen
fest. Solange das Basismodul nicht steht, ist der endgültige Platinenumriss
offen.

Die heutigen Layoutvorgaben stehen in
[04_PCB-Layout-Empfehlung.md](04_PCB-Layout-Empfehlung.md); sie sind beim
Entwurf des Basismoduls gegenzulesen.

---

## 9 · Ehrlicher Stand

**Nichts davon ist je auf echter Hardware gelaufen.** Die Firmware ist
vollständig und dokumentiert, Schaltplan und Stückliste stehen, die
Bedienoberfläche ist am Bildschirm abgenommen — aber es gibt noch kein
gebautes Gerät.

Das größte offene Risiko ist die **Masse**: rund 45 g, während
funktionierende Roboter dieser Bauart bei 10–25 g liegen. Er wird fahren,
aber vermutlich kriechen statt flitzen. Die Gegenmaßnahmen sind
beschrieben und teilweise kostenlos (dünnere Platine, kleinere LEDs); der
größte Einzelhebel wäre später ein SMD-Modul statt des gesteckten
Entwicklerboards, was 8 g spart und weder Pinbelegung noch Firmware
ändert.

Alle Entscheidungen, auch die verworfenen, stehen mit Begründung im
[Projekt-Log](../00_Projekt-Log.md).

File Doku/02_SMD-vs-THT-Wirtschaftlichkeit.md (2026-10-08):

# Wirtschaftlichkeits- und Layout-Empfehlung: SMD vs. THT

Alle Preise sind **Richtwerte in Euro, Stand Oktober 2026, ohne Versand**, aus
europäischen Distributoren (Reichelt / Berrybase / Mouser). Bei AliExpress liegen
die Modulpreise rund 40 % darunter, dafür mit Lieferzeit und Qualitätsstreuung.

---

## 1 · Die drei realistischen Wege

| | **A — DevKit 30-Pin, gesteckt** | **B — ESP32-WROOM-32E, SMD** | **C — ESP32-C3-MINI-1, SMD** |
|---|---|---|---|
| Modul | NodeMCU DevKit V1 | WROOM-32E, kastelliert | C3-MINI-1 |
| Löten | Buchsenleiste, Lötkolben | Lötkolben oder Heißluft | Heißluft empfohlen |
| USB/Programmierung | **schon drauf** | CH340C + USB-C + 2 Taster | **im Chip** (USB-Serial-JTAG) |
| Masse Modulgruppe | ≈ **10,5 g** | ≈ **2,7 g** | ≈ **1,8 g** |
| Bauhöhe über PCB | ≈ 13 mm (mit Buchse) | ≈ 3,2 mm | ≈ 2,5 mm |
| Klassisches Bluetooth | ja | ja | **nein, nur BLE** |
| Pinplan aus deinem Entwurf | passt | passt | **muss neu** |

---

## 2 · Stückkosten des Elektronikpfads

Verglichen wird nur, was sich zwischen den Varianten **unterscheidet**: Modul,
Programmierweg und Spannungsaufbereitung. Sensoren, Motoren, Treiberstufe, LEDs
und Ladeschaltung sind in allen drei Varianten identisch und stehen in der
[Stückliste](03_Stueckliste-BOM.md).

### Einzelstück (n = 1)

| Position | A · DevKit | B · WROOM | C · C3-MINI |
|---|---|---|---|
| Modul | 5,50 | 2,80 | 1,90 |
| 2× Buchsenleiste 15-pol | 0,60 | — | — |
| CH340C + Quarzlos-Beschaltung | — | 0,45 | — |
| USB-C-Buchse + 2× 5,1 kΩ | — | 0,60 | 0,60 |
| Taster BOOT + EN, RC-Glied | — | 0,40 | 0,40 |
| 5-V-Step-Up MT3608 (Modul) | 1,20 | — | — |
| 3,3-V-Buck-Boost TPS63020 + L + C | — | 2,50 | 2,50 |
| **Summe** | **7,30** | **6,75** | **5,40** |

### Bei 10 Stück (pro Einheit)

| Position | A · DevKit | B · WROOM | C · C3-MINI |
|---|---|---|---|
| Modul | 4,90 | 2,40 | 1,60 |
| Peripherie wie oben | 1,70 | 3,60 | 3,20 |
| **Summe Teile** | **6,60** | **6,00** | **4,80** |
| PCB (JLCPCB, 5er-Charge umgelegt) | 0,70 | 0,70 | 0,70 |
| **Gesamt** | **7,30** | **6,70** | **5,50** |

### Bei 100 Stück (pro Einheit)

| Position | A · DevKit | B · WROOM | C · C3-MINI |
|---|---|---|---|
| Modul | 4,20 | 2,20 | 1,45 |
| Peripherie | 1,50 | 3,20 | 2,85 |
| PCB | 0,35 | 0,35 | 0,35 |
| Bestückung (JLCPCB PCBA, Setup umgelegt) | — *(Handlöten)* | 1,10 | 1,10 |
| Handlötzeit (bewertet mit 20 €/h) | 5,00 *(15 min)* | 1,70 *(5 min Nacharbeit)* | 1,70 |
| **Gesamt** | **11,05** | **8,55** | **7,45** |

---

## 3 · Die Zahlen gelesen

**Bei Einzelstück und Kleinserie kostet SMD praktisch dasselbe wie THT.** Das ist
das überraschende Ergebnis: das WROOM-Modul ist 2,70 € billiger als das DevKit,
aber USB-Buchse, USB-UART-Brücke, zwei Taster und ein ordentlicher Buck-Boost
fressen diesen Vorsprung fast vollständig auf. Die Kostenfrage entscheidet
also **nicht**.

Entschieden wird über drei andere Dinge:

**Risiko und Zeit.** Im DevKit-Pfad gibt es keine Inbetriebnahme der
USB-Schnittstelle: Kabel rein, Code drauf. Im SMD-Pfad kommen CH340C-Treiber,
Auto-Reset-Schaltung (DTR/RTS auf EN und IO0) und ein Boot-Taster dazu — alles
Standard, aber alles Dinge, die beim ersten PCB-Dreh schiefgehen können. Für
einen Erstaufbau ist das vermeidbares Risiko.

**Reparierbarkeit.** Ein gesteckter DevKit ist in zehn Sekunden getauscht. Ein
verlötetes WROOM-Modul bekommt man ohne Heißluft nicht mehr sauber herunter.

**Gewicht.** Und das ist bei diesem Projekt kein Komfortmerkmal, sondern die
Funktionsgrenze — siehe nächster Abschnitt.

### Wirtschaftliche Kippstelle

Die Handlötzeit macht den Unterschied. Pro Gerät 15 Minuten Buchsenleisten,
Widerstände, LEDs und Dioden einlöten rechnet sich bis etwa 10 Stück. Ab
**ca. 20 Stück** wird eine SMD-Baugruppe mit maschineller Bestückung billiger,
ab **50 Stück** ist es nicht mehr diskutabel.

---
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

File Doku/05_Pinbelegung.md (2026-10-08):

# Pinbelegung — ESP32 DevKit V1, 30-Pin

Maßgeblich ist `Firmware/MarsRover/Config.h`. Diese Tabelle muss damit
übereinstimmen; im Zweifel gilt die Header-Datei.

---

## Belegte Pins

| GPIO | Richtung | Funktion | Bauteile | Kennwerte |
|---|---|---|---|---|
| **32** | PWM out | Motor **links** | R1 100 Ω → Gate Q1, R3 100 kΩ nach GND | 20 kHz, 10 bit, Duty ≤ 613 |
| **33** | PWM out | Motor **rechts** | R2 100 Ω → Gate Q2, R4 100 kΩ nach GND | 20 kHz, 10 bit, Duty ≤ 613 |
| **34** | Analog in | Liniensensor **links** | Emitter OS1, R7 10 kΩ nach GND | ADC1_CH6, 12 bit, 11 dB |
| **35** | Analog in | Liniensensor **rechts** | Emitter OS2, R8 10 kΩ nach GND | ADC1_CH7, 12 bit, 11 dB |
| **14** | Digital out | LED gelb vorne **links** | R9 220 Ω → LED1 → GND | ≈ 6 mA |
| **27** | Digital out | LED gelb vorne **rechts** | R10 220 Ω → LED2 → GND | ≈ 6 mA |
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

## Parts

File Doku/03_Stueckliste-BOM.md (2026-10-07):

# Stückliste (BOM)

Für **Variante A**: ESP32 DevKitC V4 (38-Pin) gesteckt, 2× TCRT5000,
WLAN-Fernsteuerung. Preise sind Richtwerte in Euro für Einzelstück,
europäische Distributoren, Stand Oktober 2026, ohne Versand.

> Stand 06.10.2026. Maßgeblich ist der Schaltplan `pcb/MarsRover.kicad_sch`;
> im Zweifel gilt dessen Netzliste, nicht diese Tabelle.

Bauteilkürzel (`U1`, `R5` …) entsprechen der
[Netzliste](../Hardware/Netzliste.md) und der [Pinbelegung](05_Pinbelegung.md).

---

## 1 · Rechenkern

| Pos | Bauteil | Menge | Bauform | € | Bemerkung |
|---|---|---|---|---|---|
| U1 | **ESP32 DevKitC V4, 38-Pin** (AZ-Delivery) | 1 | THT, gesteckt | 5,50 | Reihenabstand **25,4 mm**, Platinenlänge 54,4 mm. Begründung in [09](09_Boardwahl-DevKitC-V4.md) |
| — | Buchsenleiste 19-pol, RM 2,54, gerade | 2 | THT | 0,80 | U1 steckbar halten, nicht einlöten |

> Das DevKit bringt USB-Buchse, CP2102/CH340 und den 3,3-V-Regler AMS1117 selbst
> mit. Deshalb fehlen in dieser Stückliste USB-UART-Brücke und Boot-Taster.

---

## 2 · Laden und Spannungsversorgung

### 2a · Variante „diskret auf eigenem PCB"

| Pos | Bauteil | Menge | Bauform | € | Bemerkung |
|---|---|---|---|---|---|
| U2 | TP4056 Lade-IC | 1 | SOP-8 | 0,45 | 1-zelliger LiPo-Lader, 4,2 V |
| U3 | DW01A Schutz-IC | 1 | SOT-23-6 | 0,35 | Tiefentladung, Überladung, Kurzschluss |
| U4 | FS8205A Doppel-MOSFET | 1 | SOT-23-6 | 0,45 | **Schaltelement für U3 — ohne das schützt U3 nichts** |
| J1 | USB-C-Buchse, 16-pol, nur Power | 1 | SMD | 0,45 | Mit Durchsteck-Haltelaschen wählen |
| R13, R14 | 5,1 kΩ, 1 % | 2 | 0805 | 0,02 | **Je einer von CC1 und CC2 nach GND. Pflicht, sonst keine 5 V** |
| R15 | **4,7 kΩ** (R_prog) | 1 | 0805 | 0,01 | Setzt 255 mA Ladestrom für eine 500-mAh-Zelle. Tabelle: [Review B9](01_Schaltplan-Review.md) |
| — | 10 µF + 100 nF an U2 | je 1 | 0805 | 0,05 | Ein- und Ausgangsentkopplung des Laders |
| — | LED 0805 rot + grün, je 1 kΩ | 2 | 0805 | 0,10 | Ladezustandsanzeige CHRG / STDBY, optional |

### 2b · Variante „Fertigmodul" — empfohlen für den Erstaufbau

| Pos | Bauteil | Menge | € | Bemerkung |
|---|---|---|---|---|
| U2–U4 | **TP4056-Ladeplatine mit USB-C und Schutzschaltung** | 1 | 1,50 | Enthält TP4056, DW01A, FS8205A, USB-C-Buchse und die CC-Widerstände |

> Beim Fertigmodul musst du trotzdem **R_prog tauschen**: die Module laden mit
> 1 A (1,2 kΩ, oft als `R3` bedruckt). Den 1,2-kΩ-Widerstand ablöten und 4,7 kΩ
> einsetzen. Sonst lädst du eine 500-mAh-Zelle mit 2 C.

### 2c · Schiene und Schalter

| Pos | Bauteil | Menge | Bauform | € | Bemerkung |
|---|---|---|---|---|---|
| U5 | **MT3608 Step-Up-Modul**, einstellbar | 1 | THT-Modul | 1,20 | **Wird umgebaut:** Poti raus, Festteiler rein — siehe Zeile darunter und [Inbetriebnahme Schritt 1a](07_Inbetriebnahme-und-Tuning.md) |
| — | Metallschicht **110 kΩ** und **15 kΩ**, 1 % | je 1 | 0805 oder 0207 | 0,04 | **Modulumbau U5.** Ersetzen das Trimmpoti: 110 kΩ von VOUT nach FB, 15 kΩ von FB nach GND → $0{,}6 \times (1+110/15) = 5{,}00$ V. Gehören aufs Modul, nicht auf die Platine — deshalb ohne Referenz |
| S1 | Schiebeschalter SPDT, THT | 1 | THT | 0,45 | Zwischen Akku-Schutzausgang und Eingang von U5 — nicht direkt an die Zelle |
| C1 | 100 µF / **10 V** Elektrolyt | 1 | THT, Ø 6,3 mm | 0,18 | Am Ausgang von U5. 10 V reichen bei 5 V Schiene, zweifache Reserve ist bei Alu-Elkos üblich |
| C2 | 10 µF Keramik / **25 V** | 1 | 0805 | 0,12 | **Nicht 10 V nehmen.** Ein X5R/X7R verliert unter Gleichspannung Kapazität; bei 5 V bleibt von einem 10-V-Typ oft nur die Hälfte übrig |
| C5 | 100 nF Keramik | 1 | 0805 | 0,02 | Parallel zu C1/C2. Der Alu-Elko ist oberhalb ~100 kHz wirkungslos, U5 taktet mit 1,2 MHz |
| D3 | Zenerdiode BZX55C5V6 | 1 | THT | 0,08 | *Optional, aber empfohlen:* Notbremse gegen einen falsch eingestellten U5 |
| BT1 | LiPo 3,7 V, **500 mAh**, JST-PH 2.0 | 1 | — | 7,50 | Bauform 503035. 150 mAh ist zu klein, siehe [Review B8](01_Schaltplan-Review.md) |
| J2 | JST-PH-2.0-Buchse, 2-pol, THT | 1 | THT | 0,25 | Polung zweimal prüfen — die Zellen sind nicht genormt belegt |

---

## 3 · Motortreiber

| Pos | Bauteil | Menge | Bauform | € | Bemerkung |
|---|---|---|---|---|---|
| M1, M2 | Vibrationsmotor 3 V, Ø 10 mm Münze | 2 | **abgesetzt** | 2,40 | ≈ 80 mA bei 3 V. Alternative: Zylinder 6 × 14 mm, kräftiger, aber je 2 g schwerer |
| — | **Lötaugen für M1/M2** | 2× 2 | THT, Ø 1,0 mm | — | Fußabdruck `PinHeader_1x02_P2.54mm_Vertical`. Die Motoren sitzen **nicht** auf der Platine; Litze direkt in die durchkontaktierten Löcher löten |
| Q1, Q2 | **AO3400A** Logik-MOSFET | 2 | SOT-23 | 0,20 | Low-Side-Schalter, 28 mΩ bei 4,5 V Gate, 5,7 A. **Muss ein Logic-Level-Typ sein** — 2N7000, BS170 und IRF540 sind bei 3,3 V Gate praktisch zu |
| R1, R2 | 100 Ω | 2 | 0805 | 0,02 | Gate-Widerstand, dämpft die Schaltflanke |
| R3, R4 | **100 kΩ** | 2 | 0805 | 0,02 | **Gate-Pulldown nach GND — verhindert Motorzucken beim Booten** |
| D1, D2 | **1N5819** Schottky | 2 | THT DO-41 | 0,16 | Freilauf, antiparallel zum Motor. 1N4148 wäre zulässig, aber schlechter |
| C3, C4 | 100 nF Keramik | 2 | 0805 | 0,04 | Direkt am Drain jedes MOSFETs nach GND. Das ist die Funkentstörung an der Motorklemme |
| C11, C12 | **47 µF / 10 V Elektrolyt** | 2 | THT, Ø 5 mm | 0,24 | Je Motorstufe, **von +5 V nach GND** — siehe Kasten unten |

> ### Warum die 47 µF nicht über die Motorklemmen gehören
>
> Über den Klemmen läge der Elko parallel zum MOSFET. Bei jedem Einschalten
> entlädt er sich über den FET, begrenzt nur durch ESR und Bahnwiderstand —
> das sind Ampere, und zwar **20 000-mal je Sekunde** bei 20 kHz PWM. Ein
> 47-µF-Radialelko verträgt etwa 100–200 mA Rippelstrom; er wäre in Wochen
> trocken, und der AO3400A bekäme die Stöße umsonst ab.
>
> Von **+5 V nach Masse**, direkt an der Stufe, erfüllt er denselben Zweck:
> Er liefert den Stromimpuls der Motoren örtlich und hält ihn aus dem Rest
> der Platine heraus, wo das ADC-Frontend der Liniensensoren sitzt.

---

## 4 · Liniensensorik

| Pos | Bauteil | Menge | Bauform | € | Bemerkung |
|---|---|---|---|---|---|
| OS1, OS2 | **TCRT5000** Reflexkoppler | 2 | THT, 4-pol | 0,90 | **Nackter Sensor, nicht das Modul mit LM393.** Der Regler braucht den Analogwert |
| R5, R6 | **150 Ω** | 2 | THT 1/4 W | 0,04 | Vorwiderstand der IR-LED: (3,3 − 1,25) / 150 = 13,7 mA |
| R7, R8 | 10 kΩ | 2 | THT 1/4 W | 0,04 | Emitter-Pulldown des Fototransistors. **Pflicht** — GPIO 34/35 haben keine internen Pull-Widerstände |

> **Arbeitspunkt einstellen:** Steht der Messwert über hellem Untergrund dauernd
> bei ~4095 (gesättigt), R7/R8 auf 4,7 kΩ verkleinern. Bleibt der Hub zwischen
> Linie und Untergrund unter ~150 Zählern, auf 22 kΩ vergrößern. Der Istwert ist
> in der Web-App als Balken live sichtbar.

---

## 5 · Signal-LEDs

| Pos | Bauteil | Menge | Bauform | € | Bemerkung |
|---|---|---|---|---|---|
| LED1, LED2 | LED gelb, 3 mm | 2 | THT | 0,20 | Vorne links/rechts, zeigen die Lenkbewegung. **3 mm statt 5 mm spart 0,8 g** |
| LED3, LED4 | LED rot, 3 mm | 2 | THT | 0,20 | Rücklichter, im Fahrbetrieb dauerhaft an |
| R9–R12 | 220 Ω | 4 | THT 1/4 W | 0,08 | ≈ 5 mA pro LED |

> **Kein MOSFET nötig.** ESP32-WROOM-32-Datenblatt v3.8, Tabelle 14: I_OH
> typisch **40 mA** je Pin in der Domäne VDD3P3_RTC, bei mehreren gleichzeitig
> treibenden Pins laut Fußnote 2 noch rund **29 mA**. Alle vier LED-Pins —
> GPIO 14, 25, 26, 27 — liegen in dieser Domäne. Die 40 mA gelten allerdings
> nur bei maximaler Treiberstärke; die Voreinstellung von Arduino und ESP-IDF
> ist Stufe 2 mit etwa 20 mA. Auch das reicht hier um ein Mehrfaches.

---

## 5a · Entkopplung der Spannungsversorgung

| Pos | Bauteil | Menge | Bauform | € | Bemerkung |
|---|---|---|---|---|---|
| C6 | 10 µF / 25 V Keramik | 1 | 0805 | 0,12 | Am ESP32, **VIN gegen GND**. Die Motoren hängen auf derselben 5-V-Schiene und ziehen Stromimpulse |
| C7 | 100 nF Keramik | 1 | 0805 | 0,02 | dito, HF-Anteil |
| C8 | 100 nF Keramik | 1 | 0805 | 0,02 | Am ESP32, **3V3 gegen GND**. Bulk bringt der AMS1117 des DevKits selbst mit, hier fehlt nur der schnelle Anteil |
| C9, C10 | 100 nF Keramik | 2 | 0805 | 0,04 | Je einer an OS1 und OS2 |

> **Was Kondensatoren hier nicht können:** Der dominierende Störpfad ist die
> **Masse**, nicht die Versorgung — Motorrückstrom durch die Masse, auf die
> sich der ADC bezieht. Der ADC des ESP32 misst gegen eine interne
> 1,1-V-Bandgap-Referenz, nicht gegen 3,3 V; ein verschobenes Massepotential
> verschiebt den Messwert also direkt. Dagegen hilft nur der **Sternpunkt**
> aus [04 §2](04_PCB-Layout-Empfehlung.md).
>
> Bewusst **weggelassen**: 1 µF an den Sensoren (die TCRT5000 schalten nichts,
> sie ziehen 8 mA Gleichstrom) und 10 µF an 3,3 V (doppelt gemoppelt).

---

## 6 · Platine und Mechanik

| Pos | Bauteil | Menge | € | Bemerkung |
|---|---|---|---|---|
| PCB1 | Leiterplatte 2-lagig, 50 × 38 mm, **1,0 mm FR4** | 1 | 1,40 | JLCPCB 5er-Charge ≈ 7 € gesamt. 1,0 mm statt 1,6 mm spart 2,2 g bei gleichem Preis |
| — | Zahnbürstenkopf / Borstenfeld | 2 | 3,00 | **Zwei getrennte Felder, je eines unter einem Motor** — Begründung in [02 §4](02_SMD-vs-THT-Wirtschaftlichkeit.md) |
| — | Doppelseitiges Schaumklebeband | 1 | 0,50 | Akku und Bürstenköpfe befestigen; entkoppelt auch die Vibration |

---

## 7 · Optionale Erweiterungen

| Pos | Bauteil | Menge | € | Aktivierung |
|---|---|---|---|---|
| R16, R17 | 100 kΩ, 1 % | 2 | 0,02 | Spannungsteiler VBAT → GPIO 39. `FEATURE_BATTERY_MONITOR 1` in `Config.h` |
| — | Zusätzlich 100 nF an GPIO 39 nach GND | 1 | 0,02 | Glättet den Teiler gegen Motorstörungen |
| SW2 | Taster, THT | 1 | 0,15 | Betriebsart-Umschalter an GPIO 4. `FEATURE_MODE_BUTTON 1` |

---

## Kostenübersicht

| | Einzelstück |
|---|---|
| Rechenkern | 6,30 € |
| Versorgung mit **Fertigmodul** (2b) + Schiene | 11,10 € |
| Motortreiber (inkl. C11/C12) | 3,16 € |
| Sensorik | 0,98 € |
| LEDs | 0,48 € |
| Entkopplung (5a) | 0,20 € |
| PCB + Mechanik | 4,90 € |
| **Summe** | **≈ 27,10 €** |
| davon Akku | 7,50 € |

Mit der I²C-Sensorik aus §8 kommen 7,10 € dazu: **≈ 34,20 €**.

Mit der diskreten Ladeschaltung (2a) statt des Fertigmoduls wird es etwa 0,40 €
teurer, dafür flacher und 1 g leichter — aber es kommen vier SMD-Bauteile
und eine USB-C-Buchse dazu, die gelötet werden müssen.

Bei 10 Stück liegt der Materialpreis bei etwa **21 € pro Einheit**, bei 100 Stück
bei etwa **17 €** — in beiden Fällen dominiert der Akku den Preis.

---

## Einkaufsfallen, kurz zusammengefasst

1. **TCRT5000 nackt kaufen**, nicht als Modul mit Komparator.
2. **ESP32 DevKitC V4 mit 38 Pins.** Die 30-Pin-Version hat ein anderes
   Rastermaß und eine andere Pinreihenfolge — der Schaltplan passt dann nicht.
   Vor der Platinenbestellung den Reihenabstand mit dem Messschieber
   nachmessen: Soll ist **25,4 mm**.
3. **MT3608 umbauen**, bevor er eingebaut wird: Poti auslöten, 110 kΩ / 15 kΩ
   als Festteiler einsetzen, dann im Leerlauf 5,0 V nachmessen. Ein Poti auf
   einem Vibrationsfahrzeug verstellt sich, und zwar irgendwann nach oben.
4. **R_prog am TP4056 tauschen** — Werkszustand 1 A ist für diese Zelle zu viel.
5. **USB-C braucht 2× 5,1 kΩ** an CC1 und CC2 nach GND.
6. **JST-PH-Polung prüfen.** LiPo-Konfektionierungen sind nicht genormt; falsch
   gesteckt zerstört es den Lader sofort.

---

## 8 · Sensorik am I²C-Bus (Nachtrag)

Beide Sensoren hängen am selben Bus (GPIO 21/22), die Adressen kollidieren
nicht: MPU-6050 auf `0x68`, VL53L0X auf `0x29`.

| Pos | Bauteil | Menge | € | Bemerkung |
|---|---|---|---|---|
| U6 | **GY-521** (MPU-6050) Breakout | 1 | 2,50 | Lagesensor. Pull-ups sind auf dem Modul. **Flach aufs Chassis**, nahe der Drehachse, möglichst weit weg von den Motoren |
| U7 | **GY-530 / VL53L0X** Breakout | 1 | 3,50 | Abstandssensor, Laufzeitmessung. Kommt auf den Mast |
| — | Mast: CFK-Rundstab Ø 3 mm, ca. 60 mm | 1 | 0,80 | Steif und leicht. Messing- oder Alurohr geht auch, wiegt aber mehr |
| — | Litze 0,14 mm², vieradrig, ca. 120 mm | 1 | 0,30 | Zum Sensor hinauf. **Verdrillt** und mit Schlaufe am Fuß, siehe unten |
| — | Schaumklebeband für U6 | 1 | — | aus dem Restbestand der Akkubefestigung |

**Zusammen ≈ 7,10 €**, Materialpreis steigt damit von 26,50 € auf **≈ 33,60 €**.

### Massezuwachs

| Position | Masse |
|---|---|
| GY-521 (Stiftleisten abgeknipst, flach verlötet) | 1,8 g |
| GY-530 auf dem Mast | 1,3 g |
| Mast CFK 3 mm × 60 mm | 0,6 g |
| Litze und Klebstoff | 0,8 g |
| **Summe** | **≈ 4,5 g** |

Damit steigt die Gesamtmasse von ~40 g auf **~45 g** — und davon sitzen 2 g
oben auf dem Mast. Das verschärft das in
[02 §4](02_SMD-vs-THT-Wirtschaftlichkeit.md) beschriebene Hauptrisiko.
Gegenrechnung: die dort genannte Abspeckliste (1,0-mm-PCB, 3-mm-LEDs,
300-mAh-Zelle) holt ~6,5 g zurück.

### Einkaufsfallen

1. **GY-521 mit abgeknipsten Stiftleisten verbauen.** Gesteckt wackelt das
   Modul im Vibrationsbetrieb, und genau dieses Wackeln misst der Sensor dann.
2. **VL53L0X, nicht VL53L1X.** Der L1X hat eine andere Bibliothek und eine
   andere Registerkarte. Module werden oft verwechselt.
3. **Beide Module vertragen 3,3 V.** Die üblichen Breakouts haben einen
   eigenen Regler und laufen auch an 5 V — am 3V3-Pin des DevKits sind sie
   aber sparsamer und störungsärmer.

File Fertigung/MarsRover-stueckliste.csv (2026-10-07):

Referenzen | Wert | Fussabdruck | Menge | Hinweis
BT1 | LiPo 3,7V 500mAh |  | 1
C1 | 100u/10V | Capacitor_THT:CP_Radial_D6.3mm_P2.50mm | 1
C2,C6 | 10u/25V | Capacitor_SMD:C_0805_2012Metric | 2
C3-C5,C7-C10 | 100n | Capacitor_SMD:C_0805_2012Metric | 7
C11,C12 | 47u/10V | Capacitor_THT:CP_Radial_D5.0mm_P2.00mm | 2
D1,D2 | 1N5819 | Diode_THT:D_DO-41_SOD81_P7.62mm_Horizontal | 2
J2 | JST-PH 2,0 | Connector_JST:JST_PH_S2B-PH-K_1x02_P2.00mm_Horizontal | 1
LED1 | gelb - vorne links | LED_THT:LED_D3.0mm | 1
LED2 | gelb - vorne rechts | LED_THT:LED_D3.0mm | 1
LED3 | rot - hinten links | LED_THT:LED_D3.0mm | 1
LED4 | rot - hinten rechts | LED_THT:LED_D3.0mm | 1
M1 | Vibrationsmotor links | Connector_PinHeader_2.54mm:PinHeader_1x02_P2.54mm_Vertical | 1 | Motor sitzt abgesetzt, Anschluss ueber zwei Loetaugen
M2 | Vibrationsmotor rechts | Connector_PinHeader_2.54mm:PinHeader_1x02_P2.54mm_Vertical | 1 | Motor sitzt abgesetzt, Anschluss ueber zwei Loetaugen
OS1 | TCRT5000 links | OptoDevice:Vishay_TCRT5000 | 1
OS2 | TCRT5000 rechts | OptoDevice:Vishay_TCRT5000 | 1
Q1,Q2 | AO3400A | Package_TO_SOT_SMD:SOT-23 | 2
R1,R2 | 100R | Resistor_SMD:R_0805_2012Metric_Pad1.20x1.40mm_HandSolder | 2
R3,R4,R16,R17 | 100k | Resistor_SMD:R_0805_2012Metric_Pad1.20x1.40mm_HandSolder | 4
R5,R6 | 150R | Resistor_SMD:R_0805_2012Metric_Pad1.20x1.40mm_HandSolder | 2
R7,R8 | 10k | Resistor_SMD:R_0805_2012Metric_Pad1.20x1.40mm_HandSolder | 2
R9-R12 | 220R | Resistor_THT:R_Axial_DIN0207_L6.3mm_D2.5mm_P7.62mm_Horizontal | 4
S1 | Schiebeschalter | Button_Switch_THT:SW_Slide_SPDT_Straight_CK_OS102011MS2Q | 1
U1 | ESP32-DevKitC V4 | PCM_Espressif:ESP32-DevKitC | 1
U2 | TP4056-Modul | Connector_PinHeader_2.54mm:PinHeader_1x06_P2.54mm_Vertical | 1
U5 | MT3608 auf 5,00V | Connector_PinHeader_2.54mm:PinHeader_1x04_P2.54mm_Vertical | 1
U6 | GY-521 MPU-6050 | Connector_PinHeader_2.54mm:PinHeader_1x04_P2.54mm_Vertical | 1
U7 | GY-530 VL53L0X | Connector_PinHeader_2.54mm:PinHeader_1x04_P2.54mm_Vertical | 1

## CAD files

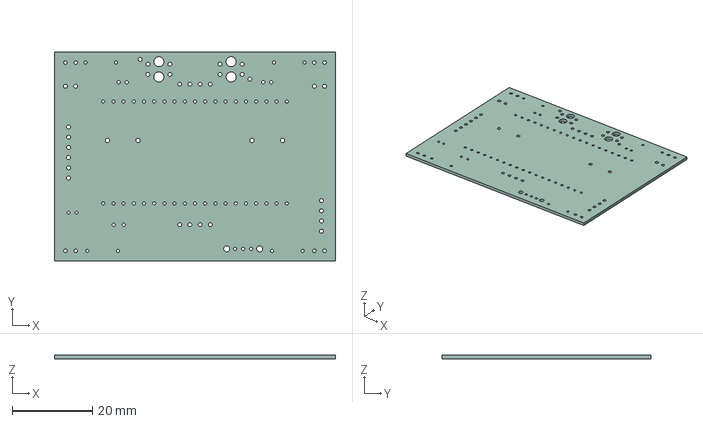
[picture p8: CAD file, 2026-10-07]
Fertigung/MarsRover-platine.step
70.0 x 52.0 x 0.91 mm

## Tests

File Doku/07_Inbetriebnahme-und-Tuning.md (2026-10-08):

# Inbetriebnahme und Tuning

---

## 1 · Software vorbereiten

### Arduino IDE

1. Boardverwalter-URL eintragen und **esp32 by Espressif** installieren
   (Core 2.0.x oder 3.x — die Firmware ist für beide ausgelegt, die LEDC-API
   wird per `#if` umgeschaltet).
2. Bibliotheksverwalter: **WebSockets** von *Markus Sattler* („arduinoWebSockets"),
   Version ≥ 2.4.1. Das ist die **einzige** externe Abhängigkeit, alles andere
   ist Teil des Cores.
3. Ordner `Firmware/MarsRover/` öffnen (`MarsRover.ino` anklicken, die `.h`-
   und `.cpp`-Dateien erscheinen als Tabs).
4. Board: **ESP32 Dev Module**, Flash Size 4 MB, Partition Scheme
   *Default 4MB with spiffs*, Upload Speed 921600.

### PlatformIO

`Firmware/platformio.ini` ist vorbereitet — `pio run -t upload` genügt, die
Bibliothek wird automatisch geholt.

---

## 2 · Hardware schrittweise in Betrieb nehmen

> Jeden Schritt einzeln abschließen. Bei Vibrationsmotoren und einem knapp
> bemessenen Step-Up ist „alles zusammenstecken und einschalten" ein guter Weg,
> ein DevKit zu verlieren.

### Schritt 1a — Poti am MT3608 raus, Festteiler rein

> **Vor dem Einbau von U5 machen, nicht danach.** Am eingebauten Modul kommst
> du an die Lötstellen des Potis nicht mehr heran, und ausgelötet wird es
> liegend auf dem Tisch in zwei Minuten.

Das Trimmpoti auf dem MT3608-Modul hat zwei Nachteile auf genau diesem Gerät:
es ist das höchste Bauteil des Moduls und stört, wenn das Modul als Finne
senkrecht steht — und es ist ein **mechanisch verstellbarer Kontakt auf einem
Fahrzeug, das seine Fortbewegung aus Vibration erzeugt**. Ein wandernder
Schleifer heißt hier wandernde Versorgungsspannung, im schlechten Fall nach
oben, und am 5-V-Pin des DevKits ist das kein kosmetisches Problem.

Deshalb: **Poti auslöten und durch einen festen Spannungsteiler ersetzen.**

Der MT3608 regelt seinen FB-Pin auf 0,6 V:

$$V_\text{aus} = 0{,}6\,\text{V} \times \left(1 + \frac{R_\text{oben}}{R_\text{unten}}\right)$$

| | Wert | Lage |
|---|---|---|
| $R_\text{oben}$ | **110 kΩ** | von **VOUT nach FB** — dorthin, wo das Poti saß |
| $R_\text{unten}$ | **15 kΩ** | von **FB nach GND** |

Nachgerechnet: $0{,}6 \times (1 + 110/15) = 0{,}6 \times 8{,}333 = \mathbf{5{,}00\ V}$.

**Drei Punkte, die dabei schiefgehen können:**

1. **Der werkseitige untere Widerstand muss raus.** Das Modul hat schon einen
   Widerstand von FB nach GND. Bleibt er liegen, steht er *parallel* zu den
   15 kΩ, der untere Zweig wird kleiner und die Ausgangsspannung **steigt**.
   Also: den Platz des alten unteren Widerstands für die 15 kΩ benutzen, nicht
   einfach zusätzlich bestücken.
2. **1 %-Metallschicht nehmen, nicht 5 %.** Der Teiler ist mit 125 kΩ
   hochohmig; dazu kommt die Toleranz der 0,6-V-Referenz. Mit 1 % landet man
   realistisch bei 4,9–5,1 V, mit 5 % kann es 4,7–5,3 V werden.
3. **Kurze Beine.** Ein hochohmiger Rückkopplungsknoten mit langen Drähten
   neben einem 1,2-MHz-Schaltregler fängt sich Störungen ein und der Regler
   fängt an zu pfeifen. Die Widerstände direkt an den Pads anlöten, nicht an
   Draht hängen lassen.

### Schritt 1b — nachmessen, **bevor** der ESP32 dran kommt

Akku an U5 anschließen, Ausgang **unbelastet** lassen, mit dem Multimeter
messen. Soll: **5,0 V ± 0,15 V**.

Steht dort deutlich mehr, ist Punkt 1 von oben passiert — abklemmen und den
unteren Zweig nachsehen. Steht dort 20 V oder mehr, hat das Modul noch seine
Werkseinstellung, der Teiler ist also nicht wirksam. **In beiden Fällen den
ESP32 nicht anschließen** — das tötet das DevKit sofort.

Erst wenn die Spannung stimmt: die optionale Zenerdiode D3 einlöten und das
Modul einbauen.

### Schritt 2 — Laden prüfen

USB-C anstecken. Lade-LED muss an sein. Sind die CC-Widerstände (R13/R14) nicht
gesetzt, passiert mit einem USB-C-Netzteil **nichts** — zum Gegentest ein
altes USB-A-Kabel verwenden, das funktioniert auch ohne CC.
Ladestrom am besten einmal in Reihe messen: soll ≈ 255 mA sein, nicht 1 A.

### Schritt 3 — DevKit allein, ohne Motoren und Sensoren

Firmware flashen. Serielle Konsole auf 115200 Baud, es muss erscheinen:

```
One-of-a-Kind Mars Rover startet
AP   : MarsRover_A3F2 / marsrover
URL  : http://192.168.4.1/
Duty : max 613 von 1023 (3.0 V Motor an 5.0 V Schiene)
Kal. : FEHLT
Prog : Platz 1 "", 0 Schritte
IMU  : nicht gefunden
Dist : nicht gefunden
```

`IMU` und `Dist` melden „gefunden", sobald die beiden I²C-Platinchen
angeschlossen sind. Auf einem nackten DevKit stehen dort „nicht gefunden",
und das ist kein Fehler — die Firmware läuft trotzdem durch.

Handy ins WLAN, Seite aufrufen, Statuspunkt muss grün werden. Wenn das steht,
funktioniert die halbe Anlage.

### Schritt 4 — LEDs

Noch gesperrt: die roten Rücklichter pulsen langsam im Sekundentakt. Nach
*Freigeben* leuchten sie dauerhaft. Tut eine LED nichts: Polung prüfen
(lange Anode an den Vorwiderstand).

### Schritt 5 — Sensoren

Noch ohne Motoren. In der Web-App auf *Autonom* schalten und die Sensorbalken
beobachten, während du die Platine über helles Papier und über ein schwarzes
Isolierband hältst.

* Balken bewegen sich nicht → Sensor falsch gepolt, oder R5/R6 fehlen
  (IR-LED bekommt keinen Strom), oder R7/R8 fehlen
* Balken dauerhaft am Anschlag → R7/R8 auf 4,7 kΩ verkleinern
* Hub zwischen Linie und Papier zu klein → R7/R8 auf 22 kΩ vergrößern, oder der
  Abstand zum Boden ist zu groß (Optimum ≈ 2,5 mm)

### Schritt 6 — Motoren

Jetzt erst Q1/Q2, Motoren, Dioden und Elko. Einschalten und **genau hinsehen:
die Motoren müssen beim Booten stillstehen.** Zucken sie, fehlen die
Basis-Pulldowns R3/R4.

Dann *Manuell*, *Freigeben*, Joystick langsam nach oben: beide Motoren müssen
gleichmäßig anlaufen.

### Schritt 7 — Funktionstest laufen lassen

Zum Abschluss der Montage und bei jeder späteren Fehlersuche: in der
Weboberfläche ganz unten **Funktionstest starten** (die Freigabe muss
gesetzt sein, weil Motoren anlaufen).

Der Test läuft in Schleife, bis du ihn stoppst, und zeigt den aktuellen
Abschnitt im Klartext an:

| Abschnitt | Dauer | Was zu sehen sein muss |
|---|---|---|
| LED vorne links | 0,7 s | nur LED1 leuchtet |
| LED vorne rechts | 0,7 s | LED1 **und** LED2 |
| LED hinten links | 0,7 s | dazu LED3 |
| LED hinten rechts | 0,7 s | alle vier leuchten |
| alle LEDs blinken | 3 s | alle vier im Gleichtakt, 2 Hz |
| Motor links | 3 s | **nur** der linke Motor, langsam anlaufend bis Vollgas; dabei leuchtet die vordere **linke** LED |
| Motor rechts | 3 s | dasselbe rechts, mit der vorderen **rechten** LED |
| Lagesensor: Drehung rechts | 1,8 s | Roboter dreht sich nach rechts, angezeigt wird die gemessene Kursänderung |
| Lagesensor: Drehung links | 1,8 s | dasselbe nach links 2013 damit wird auch die **Drehrichtung** geprüft |
| Abstandssensor | 4 s | Motoren aus, vordere LEDs an, der Messwert läuft live mit |

Dazwischen liegen kurze Pausen, damit die Abschnitte auseinanderzuhalten sind.

**Warum die LED beim Motortest mitleuchtet:** Sie zeigt, welche Seite gerade
*angesteuert* wird. Vibriert der rechte Motor, während die linke LED
leuchtet, sind Motor und Seite vertauscht verdrahtet — ein Fehler, der sich
im Fahrbetrieb nur als „lenkt falschherum" äußert und dort schwer
zuzuordnen ist.

Weitere typische Befunde:

| Beobachtung | Ursache |
|---|---|
| eine LED bleibt dunkel | Polung vertauscht, Vorwiderstand oder Lötstelle |
| beide Motoren laufen gleichzeitig | Transistoren oder PWM-Leitungen verbunden/vertauscht |
| Motor startet erst spät in der Rampe | normal — das ist genau die Haftreibung, gegen die die *Anlaufschwelle* eingestellt wird |
| Motor läuft gar nicht an | Transistor, Freilaufdiode verpolt, oder 5-V-Schiene bricht ein |
| ESP32 startet während der Motorrampe neu | Brownout: Step-Up am Anschlag. Siehe [Review B2](01_Schaltplan-Review.md) |

Nach den beiden Drehabschnitten und nach der Abstandsmessung steht unter dem
Testknopf ein Urteil im Klartext:

| Meldung | Bedeutung |
|---|---|
| **in Ordnung** | Sensor antwortet und die Werte passen |
| **keine Reaktion – Sensor oder Antrieb** | Es wurde keine Drehung gemessen. Zwei mögliche Ursachen: der Kreisel liefert nichts, **oder** der Roboter hat sich mechanisch gar nicht gedreht. Erst nachsehen, ob er sich überhaupt bewegt hat |
| **Drehrichtung vertauscht** | Der Kreisel zählt andersherum. Jede Winkeldrehung im Fahrprogramm würde in die falsche Richtung gehen — der Sensor ist um 180° verdreht montiert |
| **Sensor meldet sich nicht** | Am I²C-Bus antwortet nichts. Verdrahtung SDA und SCL, Versorgung, Lötstellen prüfen |
| **nichts im Messbereich** | Der Abstandssensor lebt, hatte aber nichts zwischen 40 und 1200 mm vor sich. Hand davorhalten und erneut laufen lassen |

**Der Drehrichtungstest ist der wertvollste Teil.** Ein um 180° verdreht
montierter Lagesensor fällt sonst erst beim ersten Fahrprogramm auf — und
dort sieht es aus wie ein Programmierfehler, nicht wie ein Montagefehler.

### Vor dem ersten Drehbefehl: Nullpunkt aufnehmen

Im Experten-Bereich **Lagesensor nullen** antippen und den Roboter dabei
1,2 Sekunden ruhig stehen lassen. Der Wert landet im Flash und überlebt
Neustarts. Ohne ihn melden die Messwerte „Nullpunkt fehlt" und der Kurs
driftet sichtbar weg.

### Abstandssensor ausrichten

In den Messwerten steht der Abstand live. Bei freier Strecke muss dort
**„frei"** stehen. Zeigt er stattdessen einen festen Wert um 100–200 mm,
blickt der Sensor auf den Tisch — der Mast ist zu stark nach unten geneigt.

Der Funktionstest ist fest in der Firmware verdrahtet, belegt keinen der
vier Programmplätze und lässt sich nicht versehentlich löschen.

---

## 3 · Kalibrierung der Linie

Pflicht vor der ersten autonomen Fahrt — ohne gültige Kalibrierung fährt der
Roboter gar nicht und die Statuszeile zeigt „nicht kalibriert".

1. Betriebsart *Autonom*, Roboter **gesperrt** lassen.
2. **Linie kalibrieren** antippen. Alle vier LEDs blinken schnell.
3. Innerhalb der 5 Sekunden den Roboter langsam quer über die Linie hin und her
   schwenken, so dass **beide** Sensoren einmal die schwarze Linie und einmal
   den hellen Untergrund sehen.
4. Blinken endet. Statuszeile darf „nicht kalibriert" nicht mehr zeigen.

Die Werte liegen im NVS-Flash und überleben Stromausfall und Neuflashen der
Firmware. Nach einem Untergrundwechsel (anderes Papier, andere Beleuchtung)
neu kalibrieren. Mit **Reset** werden sie verworfen.

Schlägt die Kalibrierung fehl, war der Hub zu klein (unter 150 ADC-Zählern) —
siehe Schritt 5 oben.

---

## 4 · Regler abstimmen

Vorgehen in dieser Reihenfolge, immer nur **einen** Wert verändern:

### 4.1 Anlaufschwelle

Betriebsart *Manuell*, Joystick ganz leicht nach oben. Die Anlaufschwelle so
weit hochziehen, bis **beide** Motoren bei kleinstem Ausschlag sicher anlaufen —
dann einen Tick zurück. Zu hoch gewählt verliert man den langsamen Bereich, zu
niedrig bleibt ein Motor stehen und der Roboter zieht zur Seite.

Laufen die Motoren unterschiedlich an, liegt das an der Serienstreuung der
Motoren, nicht an der Elektronik. Die Schwelle gilt für beide gemeinsam.

### 4.2 Grundvibration

Mit **40 %** anfangen. Das ist bewusst langsam: ein zu schneller Mars Rover
schießt über die Linie hinaus, bevor der Regler reagieren kann.

### 4.3 Kp — Lenkstärke

Von 0,2 aus in Schritten von 0,1 erhöhen, bis der Roboter die Linie zügig
zurückgewinnt.

| Symptom | Ursache | Maßnahme |
|---|---|---|
| Fährt träge über die Linie hinaus | Kp zu klein | Kp erhöhen |
| Pendelt gleichmäßig um die Linie | Kp zu groß | Kp senken oder Kd erhöhen |
| Schlägt heftig von Seite zu Seite | Kp deutlich zu groß | Kp halbieren |

### 4.4 Kd — Dämpfung

Erst wenn Kp sitzt. Kd von 0 aus in Schritten von 0,02 erhöhen, bis das
Nachpendeln verschwindet. Zu groß gewählt wird die Lenkung zappelig, weil Kd auf
das Sensorrauschen reagiert.

### 4.5 Grundvibration nachziehen

Jetzt in 10-%-Schritten hochgehen, bis es wieder unruhig wird — und eine Stufe
zurück. Höhere Geschwindigkeit braucht meist etwas mehr Kd.

Alle Werte werden 1,5 Sekunden nach der letzten Änderung automatisch ins NVS
geschrieben. Das Verzögern ist Absicht: ein Schieberegler feuert sonst Dutzende
Flash-Schreibvorgänge pro Sekunde.

### Startwerte im Code

In [`Config.h`](../Firmware/MarsRover/Config.h) stehen die Vorgabewerte
(`CTRL_KP_DEFAULT` usw.) für den Fall, dass das NVS leer ist. Hat sich ein Satz
Werte bewährt, dort eintragen.

---

## 5 · Teststrecke

* **Linie:** schwarzes Isolierband, 19 mm, auf weißem Papier oder heller Platte.
  Mattes Material — Hochglanz spiegelt die IR-LED direkt in den Fototransistor
  und verfälscht die Messung.
* **Kurvenradius:** zum Anfangen nicht unter 150 mm. Ein Vibrationsantrieb hat
  wenig Lenkautorität, 90°-Ecken sind nichts für den ersten Versuch.
* **Untergrund:** glatt und hart. Teppich frisst die Vibration vollständig.
* **Beleuchtung:** gleichmäßig. Harte Schlagschatten und direkte Sonne (viel IR!)
  verschieben den Arbeitspunkt; dann neu kalibrieren.

---

## 6 · Fehlersuche

| Symptom | Wahrscheinliche Ursache |
|---|---|
| ESP32 bootet nicht, Konsole bleibt leer | Step-Up nicht auf 5 V eingestellt. Oder (bei eigenem Pinplan) ein Treiber an GPIO 12 |
| Dauernd Neustarts im Betrieb | Brownout: Akku zu klein oder Step-Up am Anschlag. Motoren auf VBAT legen ([Review B2](01_Schaltplan-Review.md)) |
| Motoren zucken beim Einschalten | R3/R4 (Basis-Pulldown 10 kΩ) fehlen |
| Sensorbalken zittern stark, nur wenn die Motoren laufen | Masseführung: Motorrückstrom läuft über die Sensormasse. [Layout §2](04_PCB-Layout-Empfehlung.md) |
| Roboter lenkt kaum, obwohl der Duty klar unterschiedlich ist | gemeinsame Bürstenfläche statt zwei getrennter Borstenfelder |
| Roboter lenkt in die falsche Richtung | Sensoren oder Motoren vertauscht. In `Config.h` `PIN_LINE_L` und `PIN_LINE_R` tauschen |
| Fährt gar nicht los, Duty steht aber an | zu schwer oder Borsten zu steif/zu senkrecht. [02 §4](02_SMD-vs-THT-Wirtschaftlichkeit.md) |
| WLAN bricht ständig ab | Kupfer unter dem Antennenbereich des DevKits |
| App verbindet, Joystick reagiert nicht | iOS-Portalfenster. Schließen und `http://192.168.4.1` in Safari aufrufen |
| `hz` in der Statuszeile unter 200 | ungewöhnlich — Blockierung in der Schleife, serielle Debugausgabe abschalten (`FEATURE_SERIAL_DEBUG 0`) |
| USB-C lädt nicht | R13/R14 (2× 5,1 kΩ an CC1/CC2) fehlen |

---

## 7 · Noch offen

Diese Punkte sind bewusst nicht erledigt und stehen im
[Projekt-Log](../00_Projekt-Log.md):

- [ ] **Nichts davon ist in Hardware getestet.** Firmware kompiliert gegen die
      dokumentierten Core-Versionen, aber ohne Aufbau gibt es keine Messwerte.
- [ ] Schaltplan und Layout in KiCad zeichnen — die
      [Netzliste](../Hardware/Netzliste.md) ist die Vorlage dafür
- [ ] Entscheidung, ob die Motoren auf VBAT statt auf die 5-V-Schiene gehen
- [ ] Borstenwinkel und Borstenhärte empirisch ermitteln
- [ ] Startwerte für Kp/Kd/Grundvibration nach dem ersten Fahrversuch in
      `Config.h` eintragen

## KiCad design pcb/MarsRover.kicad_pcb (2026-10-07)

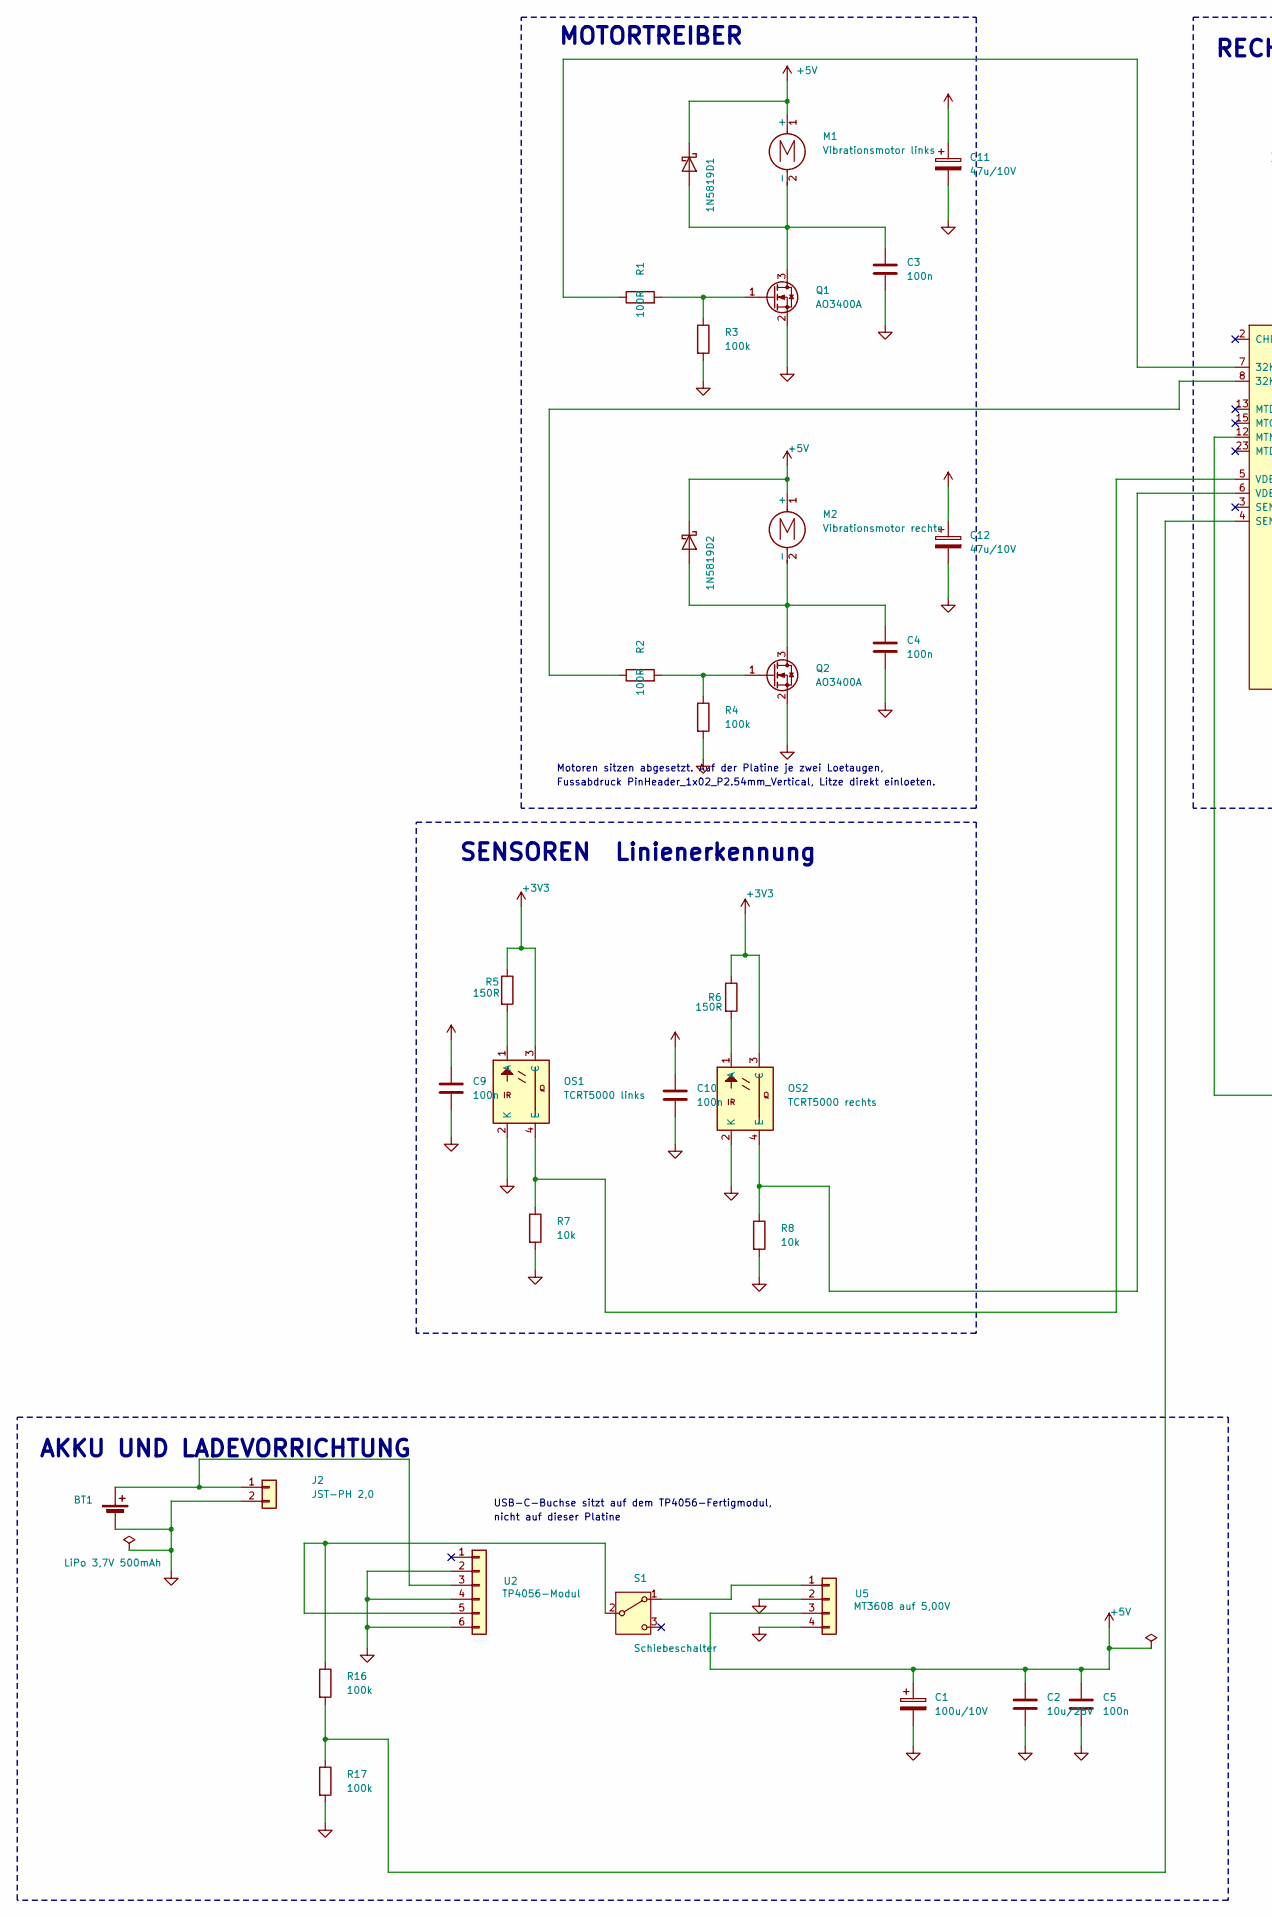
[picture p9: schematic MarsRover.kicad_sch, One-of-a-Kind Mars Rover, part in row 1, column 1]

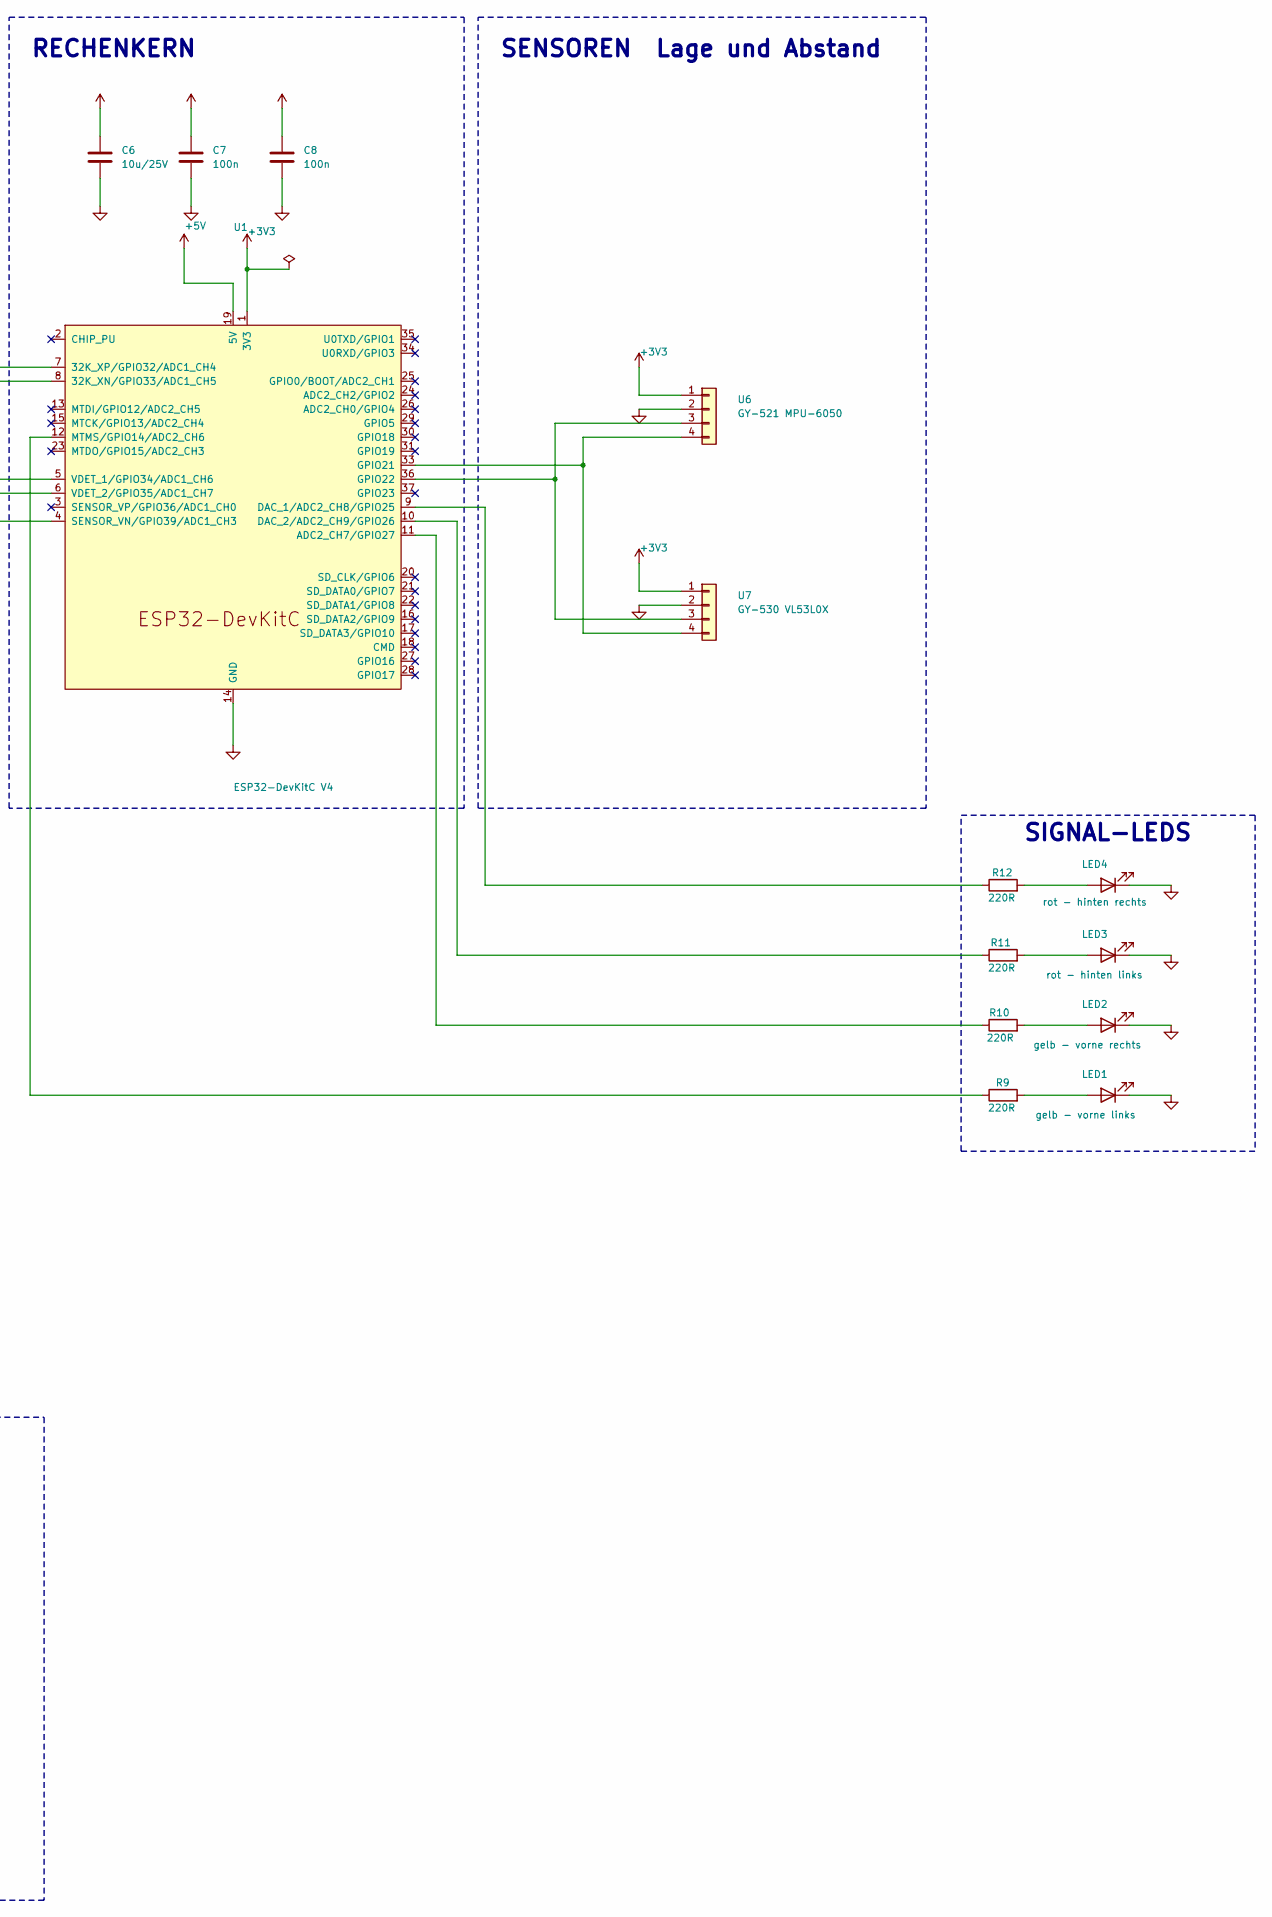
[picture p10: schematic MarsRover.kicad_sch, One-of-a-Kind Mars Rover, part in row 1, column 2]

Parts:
BT1: LiPo 3,7V 500mAh
C1: 100u/10V; CP_Radial_D6.3mm_P2.50mm
C2, C6: 10u/25V; C_0805_2012Metric
C3, C4, C5, C7, C8, C9, C10: 100n; C_0805_2012Metric
C11, C12: 47u/10V; CP_Radial_D5.0mm_P2.00mm
D1, D2: 1N5819; D_DO-41_SOD81_P7.62mm_Horizontal
J2: JST-PH 2,0; JST_PH_S2B-PH-K_1x02_P2.00mm_Horizontal
LED1: gelb - vorne links; LED_D3.0mm
LED2: gelb - vorne rechts; LED_D3.0mm
LED3: rot - hinten links; LED_D3.0mm
LED4: rot - hinten rechts; LED_D3.0mm
M1: Vibrationsmotor links; PinHeader_1x02_P2.54mm_Vertical
M2: Vibrationsmotor rechts; PinHeader_1x02_P2.54mm_Vertical
OS1: TCRT5000 links; Vishay_TCRT5000
OS2: TCRT5000 rechts; Vishay_TCRT5000
Q1, Q2: AO3400A; SOT-23
R1, R2: 100R; R_0805_2012Metric_Pad1.20x1.40mm_HandSolder
R3, R4, R16, R17: 100k; R_0805_2012Metric_Pad1.20x1.40mm_HandSolder
R5, R6: 150R; R_0805_2012Metric_Pad1.20x1.40mm_HandSolder
R7, R8: 10k; R_0805_2012Metric_Pad1.20x1.40mm_HandSolder
R9, R10, R11, R12: 220R; R_Axial_DIN0207_L6.3mm_D2.5mm_P7.62mm_Horizontal
S1: Schiebeschalter; SW_Slide_SPDT_Straight_CK_OS102011MS2Q
U1: ESP32-DevKitC V4; ESP32-DevKitC
U2: TP4056-Modul; PinHeader_1x06_P2.54mm_Vertical
U5: MT3608 auf 5,00V; PinHeader_1x04_P2.54mm_Vertical
U6: GY-521 MPU-6050; PinHeader_1x04_P2.54mm_Vertical
U7: GY-530 VL53L0X; PinHeader_1x04_P2.54mm_Vertical

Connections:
+3V3: C8.1, C9.1, C10.1, OS1.3 (C), OS2.3 (C), R5.1, R6.1, U1.1 (3V3), U6.1, U7.1
+5V: C1.1, C2.1, C5.1, C6.1, C7.1, C11.1, C12.1, D1.1 (K), D2.1 (K), M1.1 (+), M2.1 (+), U1.19 (5V), U5.3
GND: BT1.2 (-), C1.2, C2.2, C3.2, C4.2, C5.2, C6.2, C7.2, C8.2, C9.2, C10.2, C11.2, C12.2, J2.2, LED1.1 (K), LED2.1 (K), LED3.1 (K), LED4.1 (K), OS1.2 (K), OS2.2 (K), Q1.2 (S), Q2.2 (S), R3.2, R4.2, R7.2, R8.2, R17.2, U1.14 (GND), U1.32 (GND), U1.38 (GND), U2.2, U2.4, U2.6, U5.2, U5.4, U6.2, U7.2
unnamed: C3.1, D1.2 (A), M1.2 (-), Q1.3 (D)
unnamed: C4.1, D2.2 (A), M2.2 (-), Q2.3 (D)
unnamed: BT1.1 (+), J2.1, U2.3
unnamed: LED1.2 (A), R9.2
unnamed: LED2.2 (A), R10.2
unnamed: LED3.2 (A), R11.2
unnamed: LED4.2 (A), R12.2
unnamed: OS1.1 (A), R5.2
unnamed: OS1.4 (E), R7.1, U1.5 (VDET_1/GPIO34/ADC1_CH6)
unnamed: OS2.1 (A), R6.2
unnamed: OS2.4 (E), R8.1, U1.6 (VDET_2/GPIO35/ADC1_CH7)
unnamed: Q1.1 (G), R1.2, R3.1
unnamed: Q2.1 (G), R2.2, R4.1
unnamed: S1.1 (A), U5.1
unnamed: R16.1, S1.2 (B), U2.5
unnamed: R2.1, U1.8 (32K_XN/GPIO33/ADC1_CH5)
unnamed: R1.1, U1.7 (32K_XP/GPIO32/ADC1_CH4)
unnamed: R10.1, U1.11 (ADC2_CH7/GPIO27)
unnamed: R12.1, U1.9 (DAC_1/ADC2_CH8/GPIO25)
unnamed: R11.1, U1.10 (DAC_2/ADC2_CH9/GPIO26)
unnamed: U1.33 (GPIO21), U6.4, U7.4
unnamed: U1.36 (GPIO22), U6.3, U7.3
unnamed: R9.1, U1.12 (MTMS/GPIO14/ADC2_CH6)
unnamed: R16.2, R17.1, U1.4 (SENSOR_VN/GPIO39/ADC1_CH3)

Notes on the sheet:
Motoren sitzen abgesetzt. Auf der Platine je zwei Loetaugen,
MOTORTREIBER
SENSOREN Linienerkennung
USB-C-Buchse sitzt auf dem TP4056-Fertigmodul,
SIGNAL-LEDS
Fussabdruck PinHeader_1x02_P2.54mm_Vertical, Litze direkt einloeten.
AKKU UND LADEVORRICHTUNG
RECHENKERN
nicht auf dieser Platine
SENSOREN Lage und Abstand

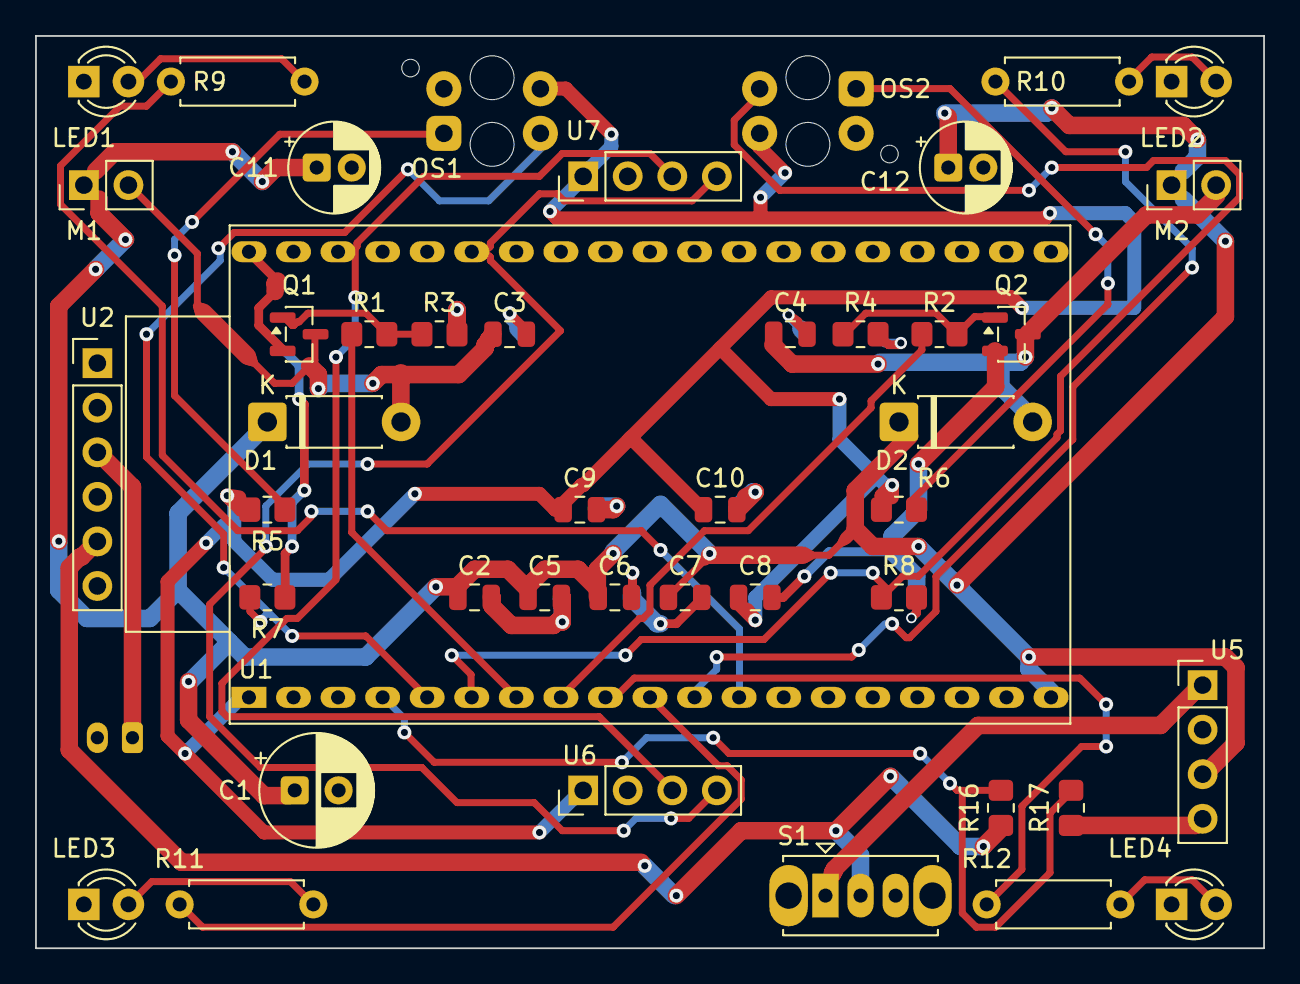
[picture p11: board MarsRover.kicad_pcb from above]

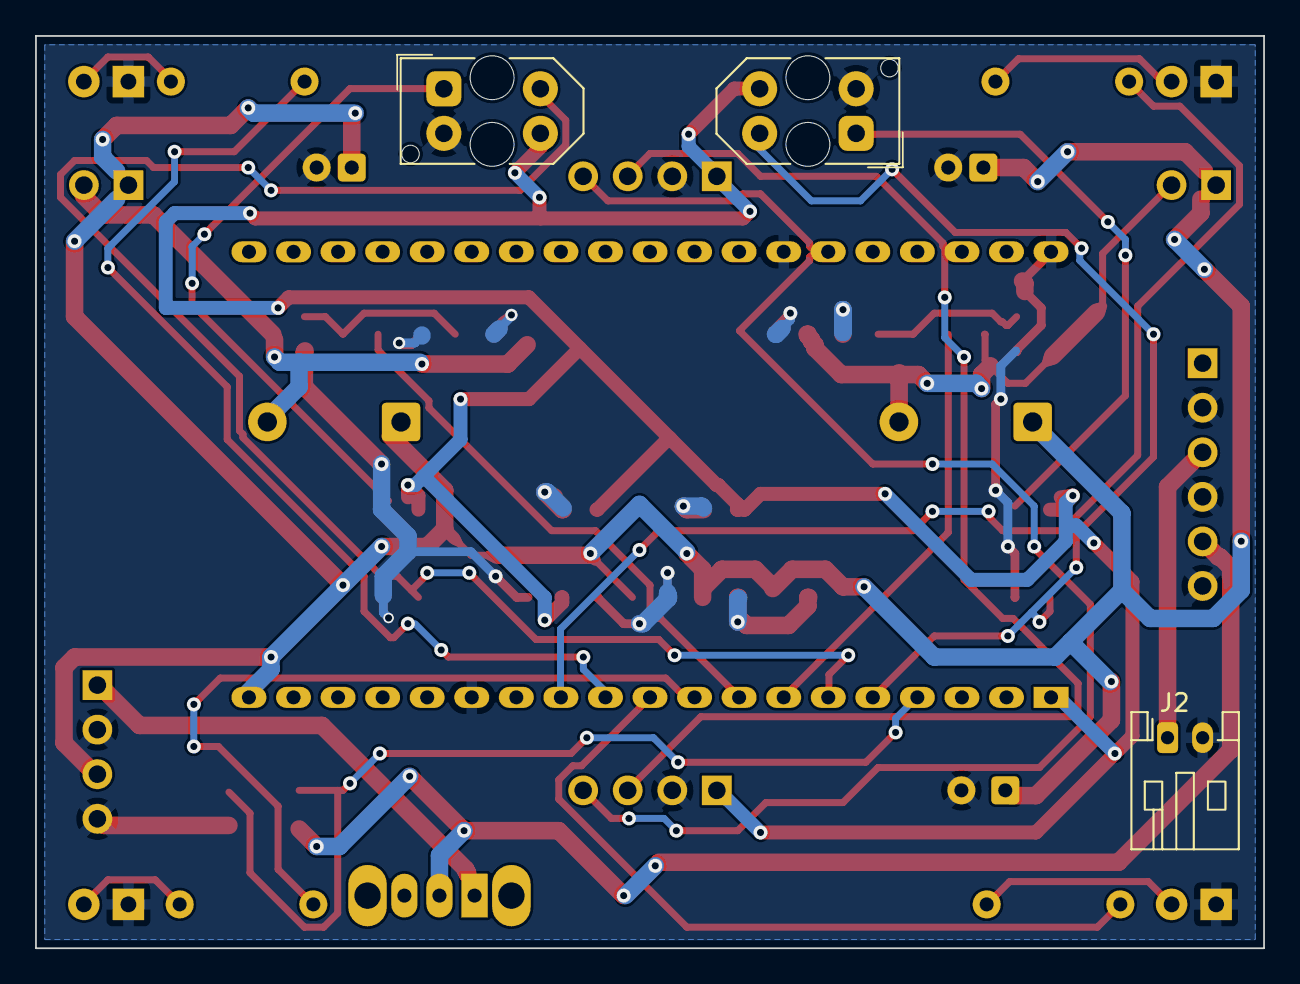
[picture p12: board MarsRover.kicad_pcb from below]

Board: 2 copper layers, 70.0 x 52.0 mm, 45 parts (3 on the bottom side), 27 nets.

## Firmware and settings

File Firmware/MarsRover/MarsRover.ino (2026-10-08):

// =====================================================================
//  O N E - O F - A - K I N D   M A R S   R O V E R
//  Linienfolgender Zahnbuersten-Roboter auf ESP32.
//  Fortbewegung wie bei einem Bristlebot -- Vibration auf schraegen
//  Borsten -- aber mit zwei Antrieben, Liniensensorik und WLAN.
//
//  Drei Betriebsarten, umschaltbar in der Web-App:
//    manuell   Joystick
//    autonom   Linienfolger mit PD-Regler
//    Programm  gespeicherter Ablauf aus einem von vier Flash-Plaetzen
//
//  Diese Datei macht nur die Orchestrierung: Zustandsmaschine, Regler,
//  Telemetrie. Alles Hardwarenahe steckt in den Modulen:
//
//    Config.h        Pins, Kennwerte, Feature-Flags  -- hier tunen
//    RobotState.h    Betriebsart, Phase, LED-Zustaende, Tuningstruktur
//    Motors.*        PWM, Kennlinienspreizung, Kickstart
//    LineSensor.*    2x TCRT5000, Median-Filter, Kalibrierung in NVS
//    Leds.*          Blinkmuster, im Programmbetrieb direkt steuerbar
//    Program.*       Fahrprogramme: Parser, vier Flash-Slots, Interpreter
//    SelfTest.*      eingebauter Funktionstest fuer die Inbetriebnahme
//    Imu.*           MPU-6050: Kurswinkel und Kippschutz (optional)
//    Distance.*      VL53L0X am Mast: Abstand nach vorn (optional)
//    RemoteControl.* Access Point, Webserver, WebSocket, Protokoll
//    WebUI.h         die Bedienoberflaeche (iPhone + Android, Browser)
//
//  Benoetigte Bibliothek (Library Manager):
//    WebSockets  von Markus Sattler ("arduinoWebSockets") >= 2.4.1
//  Alles andere ist Teil des ESP32-Arduino-Cores.
//
//  Board: "ESP32 Dev Module", Flash 4 MB, Partition "Default 4MB with spiffs"
// =====================================================================
#include "Config.h"
#include "RobotState.h"
#include "Motors.h"
#include "LineSensor.h"
#include "Leds.h"
#include "Program.h"
#include "SelfTest.h"
#include "Imu.h"
#include "Distance.h"
#include "RemoteControl.h"

// ---------------------------------------------------------------------
//  Module
// ---------------------------------------------------------------------
static Motors        motors;
static LineSensor    line;
static Leds          leds;
static Program       prog;
static SelfTest      selftest;
#if FEATURE_IMU
static Imu           imu;
#else
// Platzhalter mit derselben Schnittstelle, damit der uebrige Code
// unveraendert bleibt, wenn der Lagesensor abgewaehlt ist.
struct ImuStub {
  bool begin() { return false; }
  void update() {}
  bool present() const { return false; }
  float heading() const { return 0.0f; }
  float rate() const { return 0.0f; }
  void zeroHeading() {}
  void startCalibration() {}
  bool calibrating() const { return false; }
  bool calibrated() const { return false; }
  bool tipped() const { return false; }
  bool lifted() const { return false; }
};
static ImuStub       imu;
#endif

#if FEATURE_DISTANCE
static Distance      dist;
#else
struct DistStub {
  bool begin() { return false; }
  void update() {}
  bool present() const { return false; }
  bool valid() const { return false; }
  uint16_t mm() const { return 0; }
  bool closerThan(uint16_t) const { return false; }
};
static DistStub      dist;
#endif
static RemoteControl rc;

// ---------------------------------------------------------------------
//  Laufzeitzustand
// ---------------------------------------------------------------------
static Mode   g_mode   = Mode::Manual;
static Phase  g_phase  = Phase::Disarmed;
static bool   g_armed  = false;         // nach dem Einschalten immer gesperrt
static Tuning g_tune;

static float    g_lastError   = 0.0f;
static float    g_lastSteer   = 0.0f;
static int8_t   g_lastErrSign = 0;      // Richtung, in der die Linie zuletzt lag
static uint32_t g_lastCtrlMs  = 0;
static uint32_t g_lostSinceMs = 0;

static uint32_t g_tuneDirtyMs = 0;      // NVS-Schreiben entprellen
static uint32_t g_nextTeleMs  = 0;
static uint32_t g_loopCount   = 0;
static uint16_t g_loopHz      = 0;
static uint32_t g_hzWindowMs  = 0;

#if FEATURE_BATTERY_MONITOR
static float    g_vbat = 0.0f;
#endif
#if FEATURE_MODE_BUTTON
static uint32_t g_btnDebounceMs = 0;
static bool     g_btnLast = true;
#endif

// =====================================================================
//  Tuningwerte in NVS
// =====================================================================
static void loadTuning() {
  Preferences p;
  p.begin(NVS_NAMESPACE, true);
  g_tune.kp       = p.getFloat("kp",   CTRL_KP_DEFAULT);
  g_tune.kd       = p.getFloat("kd",   CTRL_KD_DEFAULT);
  g_tune.base     = p.getFloat("base", CTRL_BASE_DEFAULT);
  g_tune.minLevel = p.getFloat("minl", MOTOR_MIN_LEVEL_DEFAULT);
  p.end();
  motors.setMinLevel(g_tune.minLevel);
}

static void saveTuning() {
  Preferences p;
  p.begin(NVS_NAMESPACE, false);
  p.putFloat("kp",   g_tune.kp);
  p.putFloat("kd",   g_tune.kd);
  p.putFloat("base", g_tune.base);
  p.putFloat("minl", g_tune.minLevel);
  p.end();
}

// =====================================================================
//  Fahrbefehle
// =====================================================================
static inline float clamp01(float v) { return v < 0.0f ? 0.0f : (v > 1.0f ? 1.0f : v); }

// steer > 0 = nach rechts lenken. Rechtskurve heisst: linker Motor
// vibriert kraeftiger -- genau wie beim Differentialantrieb.
static void drive(float base, float steer) {
  g_lastSteer = constrain(steer, -1.0f, 1.0f);
  motors.set(clamp01(base + g_lastSteer), clamp01(base - g_lastSteer));
  leds.setSteer(g_lastSteer);
}

static void halt() {
  motors.stop();
  g_lastSteer = 0.0f;
  leds.setSteer(0.0f);
}

// ---------------------------------------------------------------------
//  Handbetrieb: Joystick mischen
// ---------------------------------------------------------------------
static void runManual() {
  const RemoteInput& in = rc.input();

  // Totmannschalter: ohne frisches Paket wird gestoppt. Verhindert, dass
  // der Roboter weiterlaeuft, wenn das Handy weggeht oder der Browser
  // in den Hintergrund wechselt.
  if (!in.connected || (millis() - in.lastPacketMs) > RC_TIMEOUT_MS) {
    halt();
    g_phase = Phase::Idle;
    return;
  }

  const float speed = in.y > 0.0f ? in.y : 0.0f;   // rueckwaerts gibt es nicht
  const float x     = in.x;

  if (speed < 0.05f) {
    if (fabsf(x) > 0.5f) {
      // Drehen auf der Stelle: nur die aeussere Seite vibriert
      if (x > 0) motors.set(PIVOT_LEVEL, 0.0f);
      else       motors.set(0.0f, PIVOT_LEVEL);
      g_lastSteer = x;
      leds.setSteer(x);
      g_phase = Phase::Running;
    } else {
      halt();
      g_phase = Phase::Idle;
    }
    return;
  }
  g_phase = Phase::Running;

  const float l = speed * (1.0f + x * MANUAL_STEER_AUTHORITY);
  const float r = speed * (1.0f - x * MANUAL_STEER_AUTHORITY);
  motors.set(clamp01(l), clamp01(r));
  g_lastSteer = x;
  leds.setSteer(x);
}

// ---------------------------------------------------------------------
//  Autonomer Linienfolger: PD-Regler auf die Sensordifferenz
// ---------------------------------------------------------------------
static void runAuto() {
  const uint32_t now = millis();

  if (!line.calibrated()) {      // ohne Kalibrierung keine Fahrt
    halt();
    g_phase = Phase::Lost;
    return;
  }

  if (line.lineVisible()) {
    g_lostSinceMs = 0;
    g_phase = Phase::Running;

    const float err = line.error();
    float dt = (now - g_lastCtrlMs) * 0.001f;
    if (dt < 0.001f) dt = 0.001f;         // Division durch Null vermeiden
    const float dErr = (err - g_lastError) / dt;
    g_lastError  = err;
    g_lastCtrlMs = now;
    if (fabsf(err) > 0.05f) g_lastErrSign = (err > 0) ? 1 : -1;

    drive(g_tune.base, g_tune.kp * err + g_tune.kd * dErr);
    return;
  }

  // Linie weg: erst pendelnd suchen, dann aufgeben
  if (g_lostSinceMs == 0) g_lostSinceMs = now;
  const uint32_t lost = now - g_lostSinceMs;

  if (lost > LINE_LOST_GIVEUP_MS) {
    halt();
    g_phase = Phase::Lost;
    return;
  }

  g_phase = Phase::Searching;
  // Zuerst in die Richtung drehen, in der die Linie zuletzt lag,
  // danach im Wechsel mit immer der anderen Seite.
  const bool flip    = ((lost / LINE_LOST_SEARCH_MS) & 1) != 0;
  const bool toRight = (g_lastErrSign >= 0) != flip;
  if (toRight) { motors.set(PIVOT_LEVEL, 0.0f); leds.setSteer(1.0f);  }
  else         { motors.set(0.0f, PIVOT_LEVEL); leds.setSteer(-1.0f); }
}

// ---------------------------------------------------------------------
//  Fahrprogramm abspielen
//
//  Der Interpreter rechnet nur aus, was er haben will -- Motoren und
//  LEDs werden hier gesetzt. So bleibt Program.* frei von Hardware.
// ---------------------------------------------------------------------
// Laufender Sensorbefehl (drehen, fahren bis Hindernis, warten bis frei)
static uint32_t g_awaitStartMs = 0;
static bool     g_awaitActive  = false;
static float    g_turnFrom     = 0.0f;
// Hindernis-Stopp als Schutzfunktion, in der Oberflaeche abschaltbar
static bool     g_obsGuard    = true;
static uint16_t g_obsGuardMm  = OBSTACLE_STOP_MM_DEFAULT;
// Kurs halten bei "geradeaus"
static uint8_t  g_holdSeq     = 255;
static float    g_holdRef     = 0.0f;

static void runProgram() {
  prog.update();

  if (!prog.running()) {
    halt();
    leds.setOverride(false);
    g_awaitActive = false;
    g_holdSeq     = 255;
    g_phase = prog.finished() ? Phase::ProgramDone : Phase::Idle;
    return;
  }

  g_phase = Phase::Running;

  // Lichter: im Programmbetrieb bestimmt der Ablauf jede LED einzeln
  leds.setOverride(true);
  for (uint8_t i = 0; i < LED_COUNT; i++) leds.setLed(i, prog.led(i));
  leds.setBlinkLevel(prog.blinkLevel());

  // ---------------- Befehle, die auf einen Sensor warten ----------------
  const Program::Await aw = prog.awaiting();
  if (aw != Program::Await::None) {

    if (!g_awaitActive) {            // erster Durchlauf dieses Befehls
      g_awaitActive  = true;
      g_awaitStartMs = millis();
      g_turnFrom     = imu.heading();
      if (aw == Program::Await::Turn && imu.present()) {
        imu.zeroHeading();           // Drift je Drehung neu nullen
        g_turnFrom = 0.0f;
      }
      g_holdSeq = 255;               // Kursregelung neu aufsetzen
    }

    const uint32_t elapsed = millis() - g_awaitStartMs;
    const float    level   = prog.awaitSpeed();
    bool done = false;

    switch (aw) {

      case Program::Await::Turn: {
        const int16_t want = prog.turnDegrees();       // + = rechts
        // Auf der Stelle drehen: nur die aeussere Seite vibriert
        if (want > 0) motors.set(level, 0.0f);
        else          motors.set(0.0f, level);
        leds.setSteer(want > 0 ? 1.0f : -1.0f);

        if (imu.present() && imu.calibrated()) {
          done = fabsf(imu.heading() - g_turnFrom) >= (fabsf((float)want) - TURN_TOLERANCE_DEG);
        } else {
          // Ohne Lagesensor bleibt nur eine Zeitschaetzung. Das ist keine
          // Winkelregelung, sondern eine Annahme -- die App sagt das auch.
          done = elapsed >= (uint32_t)(fabsf((float)want) / TURN_RATE_FALLBACK_DPS * 1000.0f);
        }
        if (elapsed > TURN_TIMEOUT_MS) done = true;
        break;
      }

      case Program::Await::Obstacle: {
        // Geradeaus, nach Moeglichkeit auf Kurs gehalten
        float s = 0.0f;
        if (imu.present() && imu.calibrated()) {
          if (g_holdSeq == 255) { g_holdSeq = prog.motionSeq(); g_holdRef = imu.heading(); }
          s = constrain(-HOLD_KP * (imu.heading() - g_holdRef), -HOLD_MAX, HOLD_MAX);
        }
        motors.set(clamp01(level + s), clamp01(level - s));
        g_lastSteer = s;

        done = dist.closerThan(prog.awaitMm())
            || elapsed > OBSTACLE_TIMEOUT_MS
            || !dist.present();        // ohne Sensor nicht erfuellbar
        break;
      }

      case Program::Await::TurnClear: {
        const int8_t dir = prog.awaitDir();
        if (dir > 0) motors.set(level, 0.0f);
        else         motors.set(0.0f, level);
        leds.setSteer(dir > 0 ? 1.0f : -1.0f);

        // "frei" heisst: nichts naeher als der Schwellwert
        done = !dist.closerThan(prog.awaitMm())
            || elapsed > OBSTACLE_TIMEOUT_MS
            || !dist.present();
        break;
      }

      case Program::Await::WaitClear:
        motors.stop();
        g_lastSteer = 0.0f;
        leds.setSteer(0.0f);
        done = !dist.closerThan(prog.awaitMm()) || !dist.present();
        break;

      default:
        done = true;
        break;
    }

    if (done) {
      g_awaitActive = false;
      motors.stop();
      prog.reportAwaitDone();
    }
    return;
  }
  g_awaitActive = false;

  // ---------------- Fahren ----------------
  if (!prog.moving()) {
    motors.stop();
    g_lastSteer = 0.0f;
    g_holdSeq   = 255;
    return;
  }

  float s = prog.steer();

  // Kurs halten, aber nur bei "geradeaus". In einer Kurve ist die
  // Drehbewegung ja genau das Gewollte.
  if (imu.present() && imu.calibrated() && fabsf(s) < 0.001f) {
    if (g_holdSeq != prog.motionSeq()) {     // neuer Geradeaus-Befehl
      g_holdSeq = prog.motionSeq();
      g_holdRef = imu.heading();
    }
    float corr = -HOLD_KP * (imu.heading() - g_holdRef);
    s = constrain(corr, -HOLD_MAX, HOLD_MAX);
  } else {
    g_holdSeq = 255;
  }

  motors.set(clamp01(prog.speed() + s), clamp01(prog.speed() - s));
  g_lastSteer = s;
}

// ---------------------------------------------------------------------
//  Funktionstest
//
//  Hat Vorrang vor allen Betriebsarten -- es ist ein Diagnosewerkzeug,
//  kein Fahrmodus. Die Freigabe braucht er trotzdem, weil Motoren laufen.
// ---------------------------------------------------------------------
static void runSelfTest() {
  selftest.update(imu.heading(), imu.present() && imu.calibrated(),
                  dist.valid() ? dist.mm() : 0, dist.present());
  g_phase = Phase::SelfTest;

  leds.setOverride(true);
  for (uint8_t i = 0; i < LED_COUNT; i++) leds.setLed(i, selftest.led(i));
  leds.setBlinkLevel(selftest.blinkLevel());

  motors.set(selftest.motorL(), selftest.motorR());
  g_lastSteer = 0.0f;
}

// =====================================================================
//  Anfragen der Web-App
// =====================================================================
static void leaveProgramMode() {
  prog.stop();
  selftest.stop();
  leds.setOverride(false);
}

static void applyRequests() {
  RcRequests q = rc.takeRequests();

  if (q.estop) {
    g_armed = false;
    leaveProgramMode();
    halt();
  }
  if (q.haveArm) {
    g_armed = q.arm;
    if (!g_armed) { leaveProgramMode(); halt(); }
  }
  if (q.haveMode && q.mode != g_mode) {
    g_mode = q.mode;
    leaveProgramMode();             // Betriebsart wechselt nie "fliegend"
    halt();
    g_lastError   = 0.0f;
    g_lostSinceMs = 0;
  }
  if (q.calibrate) {
    halt();
    line.startCalibration();
  }
  if (q.resetCal) {
    line.resetCalibration();
  }
  if (q.haveGuard) {
    g_obsGuard   = q.guard;
    g_obsGuardMm = q.guardMm;
  }
  if (q.zeroGyro) {
    halt();
    imu.startCalibration();       // Roboter muss dabei ruhig stehen
  }
  if (q.haveTuning) {
    g_tune = q.tuning;
    motors.setMinLevel(g_tune.minLevel);
    rc.publishTuning(g_tune);
    g_tuneDirtyMs = millis();       // NVS-Schreiben verzoegert, s. loop()
  }
  if (q.haveRun) {
    if (q.run) {
      // Ohne Freigabe laeuft kein Motor -- das Programm trotzdem starten
      // zu lassen waere irrefuehrend.
      selftest.stop();
      if (g_armed) prog.start();
    } else {
      leaveProgramMode();
      halt();
    }
  }
  if (q.haveTest) {
    if (q.test) {
      prog.stop();                 // Test und Fahrprogramm schliessen sich aus
      if (g_armed) selftest.start();
    } else {
      selftest.stop();
      leds.setOverride(false);
      halt();
    }
  }
}

// =====================================================================
//  Telemetrie
// =====================================================================
static void sendTelemetry() {
  char buf[460];
  int n = snprintf(buf, sizeof(buf),
    "{\"p\":%u,\"m\":%u,\"a\":%u,\"sL\":%.3f,\"sR\":%.3f,\"e\":%.3f,"
    "\"dL\":%u,\"dR\":%u,\"dMax\":%u,\"calOk\":%u,\"hz\":%u,"
    "\"pr\":%u,\"pc\":%u,\"pn\":%u,\"pass\":%u,\"slot\":%u,"
    "\"ts\":%u,\"tp\":%u,\"tv\":%u,\"ti\":%d,\"tg\":%u,\"td\":%u,"
    "\"imu\":%u,\"hd\":%.1f,\"ic\":%u,"
    "\"dsp\":%u,\"ds\":%u,\"og\":%u,\"om\":%u",
    (unsigned)g_phase, (unsigned)g_mode, g_armed ? 1u : 0u,
    line.linenessL(), line.linenessR(), line.error(),
    motors.dutyL(), motors.dutyR(), Motors::dutyMax(),
    line.calibrated() ? 1u : 0u, g_loopHz,
    prog.running() ? 1u : 0u, prog.pc(), prog.count(), prog.pass(), prog.activeSlot(),
    selftest.running() ? 1u : 0u, selftest.step(), selftest.percent(),
    selftest.info(), selftest.gyroVerdict(), selftest.distVerdict(),
    imu.present() ? 1u : 0u, imu.heading(), imu.calibrated() ? 1u : 0u,
    dist.present() ? 1u : 0u, dist.valid() ? dist.mm() : 0u,
    g_obsGuard ? 1u : 0u, g_obsGuardMm);
#if FEATURE_BATTERY_MONITOR
  n += snprintf(buf + n, sizeof(buf) - n, ",\"vb\":%.2f", g_vbat);
#endif
  snprintf(buf + n, sizeof(buf) - n, "}");

  rc.sendTelemetry(buf);

#if FEATURE_SERIAL_DEBUG
  Serial.println(buf);
#endif
}

// =====================================================================
//  setup / loop
// =====================================================================
void setup() {
#if FEATURE_SERIAL_DEBUG
  Serial.begin(115200);
  delay(150);
  Serial.println();
  Serial.println(F("One-of-a-Kind Mars Rover startet"));
#endif

  // Reihenfolge ist Absicht: erst die Motoren auf Null, dann der Rest.
  motors.begin();
  leds.begin();
  leds.setPhase(Phase::Disarmed);
  line.begin();
  loadTuning();
  prog.begin();

  // Lagesensor ist optional: fehlt er, laeuft alles weiter, nur die
  // Drehbefehle fallen auf eine Zeitschaetzung zurueck.
  const bool imuOk  = imu.begin();
  const bool distOk = dist.begin();

#if FEATURE_MODE_BUTTON
  pinMode(PIN_MODE_BTN, INPUT_PULLUP);
#endif

  rc.publishTuning(g_tune);
  rc.attachProgram(&prog);
  rc.begin();

#if FEATURE_SERIAL_DEBUG
  Serial.printf("AP   : %s / %s\n", rc.ssid(), AP_PASSWORD);
  Serial.printf("URL  : http://%s/\n", WiFi.softAPIP().toString().c_str());
  Serial.printf("Duty : max %u von %u (%.1f V Motor an %.1f V Schiene)\n",
                Motors::dutyMax(), PWM_FULL, MOTOR_RATED_V, MOTOR_SUPPLY_V);
  Serial.printf("Kal. : %s\n", line.calibrated() ? "geladen" : "FEHLT");
  Serial.printf("Prog : Platz %u \"%s\", %u Schritte\n",
                prog.activeSlot() + 1, prog.slotName(prog.activeSlot()), prog.count());
  Serial.printf("IMU  : %s%s\n", imuOk ? "MPU-6050 gefunden" : "nicht gefunden",
                (imuOk && !imu.calibrated()) ? " -- Nullpunkt fehlt, bitte nullen" : "");
  Serial.printf("Dist : %s\n", distOk ? "VL53L0X gefunden" : "nicht gefunden");
#else
  (void)imuOk; (void)distOk;
#endif

  g_lastCtrlMs = millis();
  g_hzWindowMs = millis();
  g_nextTeleMs = millis() + TELEMETRY_MS;
}

void loop() {
  const uint32_t now = millis();
  g_loopCount++;

  rc.loop();
  line.update();
  applyRequests();

#if FEATURE_MODE_BUTTON
  // Kurzer Druck schaltet die Betriebsart weiter
  const bool btn = digitalRead(PIN_MODE_BTN);
  if (btn != g_btnLast && (now - g_btnDebounceMs) > 40) {
    g_btnDebounceMs = now;
    g_btnLast = btn;
    if (btn == LOW) {
      g_mode = (g_mode == Mode::Manual) ? Mode::Auto
             : (g_mode == Mode::Auto)   ? Mode::Program
                                        : Mode::Manual;
      leaveProgramMode();
      halt();
    }
  }
#endif

#if FEATURE_BATTERY_MONITOR
  // Gleitender Mittelwert, der ADC ist durch die Motoren verrauscht
  const float v = analogReadMilliVolts(PIN_VBAT) * 0.001f * VBAT_DIVIDER;
  g_vbat = (g_vbat == 0.0f) ? v : (g_vbat * 0.99f + v * 0.01f);
#endif

  imu.update();
  dist.update();

  // ---------------- Zustandsmaschine ----------------
  if (line.calibrating()) {
    halt();
    g_phase = Phase::Calibrating;
  }
  // Umgekippt oder hochgehoben: Motoren aus und Freigabe weg. Steht vor
  // allem anderen, damit kein Betriebszustand das uebergehen kann.
  else if (imu.tipped() || imu.lifted()) {
    halt();
    g_armed = false;
    leaveProgramMode();
    g_phase = Phase::Tilted;
  }
#if FEATURE_BATTERY_MONITOR
  else if (g_vbat > 1.0f && g_vbat < VBAT_CUTOFF_V) {
    halt();
    g_armed = false;
    leaveProgramMode();
    g_phase = Phase::LowBattery;
  }
#endif
  else if (!g_armed) {
    halt();
    leaveProgramMode();             // Sperren beendet Test und Programm
    g_phase = Phase::Disarmed;
  }
  else if (selftest.running()) {
    runSelfTest();                  // Diagnose geht vor Betriebsart
  }
  // Hindernis-Stopp. Ausgenommen ist "fahre bis Hindernis" -- dieser
  // Befehl will ja gerade heranfahren.
  else if (g_obsGuard && dist.closerThan(g_obsGuardMm) &&
           prog.awaiting() == Program::Await::None) {
    halt();
    g_phase = Phase::Obstacle;
  }
  else if (g_mode == Mode::Manual) {
    runManual();                // setzt g_phase selbst (Running / Idle)
  }
  else if (g_mode == Mode::Auto) {
    runAuto();
  }
  else {
    runProgram();
  }

  leds.setPhase(g_phase);
  motors.update();
  leds.update();

  // Tuningwerte erst 1,5 s nach der letzten Aenderung sichern --
  // ein Schieberegler feuert sonst dutzende NVS-Schreibvorgaenge.
  if (g_tuneDirtyMs && (now - g_tuneDirtyMs) > 1500) {
    g_tuneDirtyMs = 0;
    saveTuning();
  }

  // Schleifenfrequenz messen (steht in der App, guter Gesundheitswert)
  if (now - g_hzWindowMs >= 1000) {
    g_loopHz = (uint16_t)g_loopCount;
    g_loopCount = 0;
    g_hzWindowMs = now;
  }

  if ((int32_t)(now - g_nextTeleMs) >= 0) {
    g_nextTeleMs = now + TELEMETRY_MS;
    sendTelemetry();
  }
}

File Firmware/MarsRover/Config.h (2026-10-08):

// =====================================================================
//  MarsRover -- Config.h
//  Zentrale Stelle fuer Pins, Kennwerte und Feature-Flags.
//  Nur hier anfassen, wenn Hardware oder Tuning sich aendert.
// =====================================================================
#pragma once
#include <Arduino.h>

// ---------------------------------------------------------------------
//  Arduino-Core-Version: die LEDC-API hat sich mit Core 3.x geaendert.
//  Dieses Flag haelt Motors.cpp fuer beide Versionen kompilierbar.
// ---------------------------------------------------------------------
#if defined(ESP_ARDUINO_VERSION_MAJOR) && ESP_ARDUINO_VERSION_MAJOR >= 3
  #define BB_LEDC_V3 1
#else
  #define BB_LEDC_V3 0
#endif

// ---------------------------------------------------------------------
//  Feature-Flags  (0 = aus; entspricht exakt dem Schaltplan ohne Extras)
// ---------------------------------------------------------------------
#define FEATURE_BATTERY_MONITOR 0   // braucht 2x 100k Spannungsteiler an GPIO39
#define FEATURE_MODE_BUTTON     0   // braucht Taster GPIO4 -> GND
#define FEATURE_SERIAL_DEBUG    1   // Telemetrie auch auf die USB-Konsole

// ---------------------------------------------------------------------
//  P I N B E L E G U N G
//
//  Abweichungen vom Originalentwurf (begruendet in Doku/01_Schaltplan-Review.md):
//    Motoren GPIO 12/13  ->  GPIO 32/33
//      GPIO12 ist Strapping-Pin (MTDI) und legt beim Reset die Flash-
//      Spannung fest. Eine Transistorbasis mit 1k daran kann das Modul
//      am Booten hindern. 32/33 haben keine Strapping-Funktion.
//    Liniensensoren auf GPIO 34/35 (ADC1). ADC2 ist bei aktivem WiFi
//      komplett gesperrt -- mit AP-Betrieb also tabu.
//    LEDs bleiben wie von dir vorgegeben (14/27/26/25).
// ---------------------------------------------------------------------
static const uint8_t PIN_MOTOR_L = 32;   // PWM -> 1k -> Basis T1 -> Motor links
static const uint8_t PIN_MOTOR_R = 33;   // PWM -> 1k -> Basis T2 -> Motor rechts

static const uint8_t PIN_LINE_L  = 34;   // ADC1_CH6, nur Eingang
static const uint8_t PIN_LINE_R  = 35;   // ADC1_CH7, nur Eingang

static const uint8_t PIN_LED_FL  = 14;   // gelb  vorne links
static const uint8_t PIN_LED_FR  = 27;   // gelb  vorne rechts
static const uint8_t PIN_LED_RL  = 26;   // rot   hinten links
static const uint8_t PIN_LED_RR  = 25;   // rot   hinten rechts

#if FEATURE_BATTERY_MONITOR
static const uint8_t PIN_VBAT      = 39;    // ADC1_CH3 ueber Teiler
static const float   VBAT_DIVIDER  = 2.0f;  // 100k / 100k
static const float   VBAT_WARN_V   = 3.40f; // ab hier rote LEDs blinken
static const float   VBAT_CUTOFF_V = 3.20f; // ab hier Motoren aus
#endif
#if FEATURE_MODE_BUTTON
static const uint8_t PIN_MODE_BTN = 4;      // gegen GND, interner Pullup
#endif

// ---------------------------------------------------------------------
//  M O T O R E N   /   P W M
// ---------------------------------------------------------------------
static const uint32_t PWM_FREQ_HZ = 20000;  // >20 kHz: kein hoerbares Pfeifen
static const uint8_t  PWM_BITS    = 10;     // 0 .. 1023
static const uint16_t PWM_FULL    = (1u << PWM_BITS) - 1;

// Spannung der Motorschiene und Nennspannung der Vibrationsmotoren.
// Daraus wird der maximal zulaessige Duty berechnet -- so kannst du
// 3V-Motoren gefahrlos an der 5V-Schiene betreiben.
static const float MOTOR_SUPPLY_V = 5.0f;
static const float MOTOR_RATED_V  = 3.0f;
static const uint16_t MOTOR_DUTY_MAX =
    (uint16_t)(PWM_FULL * (MOTOR_RATED_V < MOTOR_SUPPLY_V
                           ? MOTOR_RATED_V / MOTOR_SUPPLY_V : 1.0f));

// Unterhalb dieses Anteils dreht ein ERM-Motor wegen Haftreibung gar nicht.
// Beim Einschalten gibt es deshalb einen kurzen Volldampf-Impuls.
// Live nachstellbar in der Web-App, wird in NVS gesichert.
static const float    MOTOR_MIN_LEVEL_DEFAULT = 0.35f;
static const uint16_t MOTOR_KICK_MS           = 40;

// ---------------------------------------------------------------------
//  L I N I E N S E N S O R   (2x TCRT5000, analog)
// ---------------------------------------------------------------------
static const bool     LINE_IS_DARK   = true;  // false = helle Linie auf dunkel
static const uint8_t  LINE_SAMPLE_MS = 2;     // Abtastintervall
static const uint16_t LINE_CAL_MS    = 5000;  // Dauer der Kalibrierfahrt
static const float    LINE_PRESENT_THRESHOLD = 0.35f; // ab hier "Linie gesehen"
static const uint16_t LINE_CAL_MIN_SPAN      = 150;   // ADC-Hub, sonst Kal. ungueltig
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

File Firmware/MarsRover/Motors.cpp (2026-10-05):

#include "Motors.h"

// LEDC-Kanaele: 0 und 2, damit beide in unterschiedlichen Timern liegen
// (Kanalpaare 0/1, 2/3 ... teilen sich einen Timer).
static const uint8_t CH_L = 0;
static const uint8_t CH_R = 2;

void Motors::begin() {
#if BB_LEDC_V3
  // Arduino-ESP32 Core 3.x: Kanal wird intern vergeben
  ledcAttach(PIN_MOTOR_L, PWM_FREQ_HZ, PWM_BITS);
  ledcAttach(PIN_MOTOR_R, PWM_FREQ_HZ, PWM_BITS);
#else
  // Core 2.x: Kanal explizit konfigurieren und Pin zuweisen
  ledcSetup(CH_L, PWM_FREQ_HZ, PWM_BITS);
  ledcSetup(CH_R, PWM_FREQ_HZ, PWM_BITS);
  ledcAttachPin(PIN_MOTOR_L, CH_L);
  ledcAttachPin(PIN_MOTOR_R, CH_R);
#endif
  stop();
}

void Motors::write(uint8_t pin, uint8_t channel, uint16_t duty) {
#if BB_LEDC_V3
  (void)channel;
  ledcWrite(pin, duty);
#else
  (void)pin;
  ledcWrite(channel, duty);
#endif
}

void Motors::setMinLevel(float v) {
  _minLevel = constrain(v, 0.0f, 0.95f);
}

// Anforderung 0..1 auf den nutzbaren Duty-Bereich abbilden.
// 0 bleibt echte Null (Motor aus), alles darueber startet bei minLevel.
uint16_t Motors::shape(float request) const {
  if (request <= 0.01f) return 0;
  if (request > 1.0f)   request = 1.0f;
  const float level = _minLevel + (1.0f - _minLevel) * request;
  return (uint16_t)(level * MOTOR_DUTY_MAX);
}

void Motors::set(float left, float right) {
  const uint16_t nl = shape(left);
  const uint16_t nr = shape(right);
  const uint32_t now = millis();

  // Kickstart nur beim Uebergang Stillstand -> Lauf
  if (nl > 0 && _targetL == 0) _kickEndL = now + MOTOR_KICK_MS;
  if (nr > 0 && _targetR == 0) _kickEndR = now + MOTOR_KICK_MS;
  if (nl == 0) _kickEndL = 0;
  if (nr == 0) _kickEndR = 0;

  _targetL = nl;
  _targetR = nr;
}

void Motors::stop() {
  _targetL = _targetR = 0;
  _kickEndL = _kickEndR = 0;
  _outL = _outR = 0;
  write(PIN_MOTOR_L, CH_L, 0);
  write(PIN_MOTOR_R, CH_R, 0);
}

void Motors::update() {
  const uint32_t now = millis();

  uint16_t wantL = _targetL;
  uint16_t wantR = _targetR;
  if (_kickEndL && (int32_t)(_kickEndL - now) > 0) wantL = MOTOR_DUTY_MAX;
  if (_kickEndR && (int32_t)(_kickEndR - now) > 0) wantR = MOTOR_DUTY_MAX;

  if (wantL != _outL) { _outL = wantL; write(PIN_MOTOR_L, CH_L, _outL); }
  if (wantR != _outR) { _outR = wantR; write(PIN_MOTOR_R, CH_R, _outR); }
}

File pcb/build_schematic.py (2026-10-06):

#!/usr/bin/env python3
"""
Baut den Schaltplan des One-of-a-Kind Mars Rover auf.

GEDACHT ALS EINMALIGER AUFBAU, NICHT ALS DAUERWERKZEUG.
Danach wird der Schaltplan ueber den KiCAD-MCP-Server gepflegt --
gezielte Einzeleingriffe, damit Handaenderungen im Editor erhalten
bleiben. Ein zweiter Lauf dieses Skripts wuerde alles ueberschreiben.

Unterschied zum Vorgaenger gen_schematic.py: dort hingen die
Verbindungen an Netzlabels, die Bauteile standen ungeordnet auf dem
Blatt. Hier gilt:

  * Fuenf abgegrenzte Bereiche mit Rahmen und Ueberschrift
  * Verbindungen als GEZEICHNETE LEITUNGEN mit Knotenpunkten
  * Netzlabels kommen nicht mehr vor
  * Versorgung ueber Power-Symbole, wie in jedem Schaltplan ueblich --
    eine durchgezogene Leitung quer ueber das Blatt waere unleserlicher

Drei Dinge, die KiCad einem uebelnimmt und die hier geloest sind:

  * Alle Koordinaten muessen auf dem 1,27-mm-Raster liegen, sonst
    meldet ERC "endpoint_off_grid". Am Ende prueft das Skript das.
  * In .kicad_sym zeigt die Y-Achse nach OBEN, in .kicad_sch nach
    UNTEN. Pinkoordinaten muessen gespiegelt werden.
  * Viele Bibliothekssymbole erben per (extends ...) und haben selbst
    keine Pins. Die Vererbung wird hier aufgeloest.

Die Drehungen sind am lebenden KiCad ausgemessen, nicht geraten:

    rot   0 :  (sx + px, sy - py)
    rot  90 :  (sx - py, sy - px)
    rot 180 :  (sx - px, sy + py)
    rot 270 :  (sx + py, sy + px)
    mirror y:  x kippt      -> (sx - px, sy - py)
    mirror x:  y kippt      -> (sx + px, sy + py)

Aufruf:  "C:\Program Files\KiCad\10.0\bin\python.exe" build_schematic.py
"""

import re
import uuid
from pathlib import Path

HERE = Path(__file__).parent
KICAD_SYMBOLS = Path(r"C:\Program Files\KiCad\10.0\share\kicad\symbols")
LOCAL_LIBS = {
    "Espressif": HERE / "lib" / "Espressif.kicad_sym",
    "MarsRover": HERE / "MarsRover.kicad_sym",
}

PROJECT = "MarsRover"
PAPER = "A2"                  # 594 x 420 mm
SHEET_UUID = str(uuid.uuid4())
GRID = 1.27                   # KiCads Standardraster


# =====================================================================
#  Symbole aus den Bibliotheken holen
# =====================================================================
def lib_path(libname):
    return LOCAL_LIBS.get(libname) or KICAD_SYMBOLS / f"{libname}.kicad_sym"
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

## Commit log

2026-10-05 Projektgeruest fuer Bristlebot
    Leeres Projektverzeichnis mit README, Projekt-Log, .gitignore und GPL-3.0-Lizenz.
    Projektart (ESPHome / Custom Component / Frontend) ist noch offen und wird im
    Projekt-Log festgehalten, sobald entschieden.
2026-10-05 Firmware, Schaltplan-Review, BOM und Doku fuer den Linienfolger
    Entwurf geprueft: fuenf Blocker gefunden und behoben.
    * BluetoothSerial ist klassisches SPP und auf iOS nicht nutzbar
    -> eigener WLAN-AP, der die Bedienoberflaeche selbst ausliefert
    * dem Fototransistor fehlte die beleuchtende IR-LED -> 2x TCRT5000
    * ein Sensor kann nicht differentiell lenken -> zwei Sensoren
    * GPIO12 ist Strapping-Pin MTDI -> Motoren auf GPIO 32/33
    * USB-C ohne 2x 5k1 an CC1/CC2 liefert keine 5V -> nachgetragen
    Firmware modular, Arduino-Framework, Core 2.x und 3.x:
    Config/RobotState/Motors/LineSensor/Leds/RemoteControl/WebUI.
    PD-Regler mit Kalibrierung in NVS, Duty-Begrenzung fuer 3V-Motoren
    an der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
    [Config.h, Leds.cpp, LineSensor.cpp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]
2026-10-05 Fahrprogramme mit vier Flash-Slots und eingebauter Funktionstest
    Dritte Betriebsart: gespeicherte Ablaeufe abspielen.
    Programmsprache
    * Zeitmodell: alle Befehle wirken sofort, nur "warte" verbraucht Zeit --
    dadurch sind Fahrt und Lichter frei kombinierbar
    * jeder Fahrbefehl traegt seine Geschwindigkeit selbst
    * Kurvenradius Stufe 1 (fast auf der Stelle) bis 10 (weit)
    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
2026-10-05 Lagesensor MPU-6050 und Abstandssensor VL53L0X auf dem Mast
    Beantwortet die Frage, ob eine IMU die Steuerung genauer macht:
    ja fuer Drehungen, nein fuer Strecken. Zweifache Integration der
    Beschleunigung ist auf einem vibrationsgetriebenen Roboter binnen ein
    bis zwei Sekunden unbrauchbar -- "fahre 30 cm" bleibt unmoeglich.
    Ein LSM303DLHC am Mast wurde verworfen: er hat kein Gyroskop, sondern
    Beschleunigung plus Magnetometer. Fuer "drehe um 90 Grad" braucht es die
    Drehrate. Der Mast selbst war richtig gedacht -- das Stoerfeld faellt mit
    1/r^3 -- loest aber ein Problem, das bei Manoevern von Sekunden nicht
    auftritt: die Gyro-Drift liegt dabei unter einem Grad.
    Imu.* MPU-6050 ohne Fremd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
    [Config.h, Distance.cpp, Imu.cpp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]
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2026-10-05 Schaltplan Stufe 1: Rechenkern und Motorstufen, ERC-geprueft
    Generator erzeugt den Schaltplan aus der Netzliste. Bewusst als
    Startpunkt gedacht, nicht als Dauerwerkzeug -- danach wird in KiCad von
    Hand gepflegt, ein zweiter Lauf wuerde das ueberschreiben.
    Verdrahtet wird ueber Netzlabels an den Pins statt ueber gezeichnete
    Leitungen: bei dieser Groesse uebersichtlicher und vor allem zuverlaessig
    erzeugbar. Leitungsgeometrie zu rechnen waere die Hauptfehlerquelle.
    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
    [MarsRover.kicad_sch]
2026-10-05 Schaltplan vollstaendig: 38 Bauteile, null ERC-Fehler
    Stufe 2 ergaenzt: Liniensensoren mit Emitterfolger, vier Signal-LEDs mit
    Vorwiderstaenden, beide I2C-Module als Steckverbinder, Ladeschaltung,
    Schalter, Step-Up, Siebung und der optionale Spannungsteiler fuer die
    Akkumessung.
    106 Netzlabels, 23 Nicht-angeschlossen-Zeichen.
    ERC: null Fehler, drei Warnungen, alle erklaert:
    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
    [MarsRover.kicad_sch]
2026-10-05 Schaltplanstand aus KiCad uebernommen, Sperrdatei ausgetragen
    KiCad hat den Schaltplan beim Oeffnen und Speichern komplett neu
    geschrieben. Dieser Commit haelt genau den Stand fest, den der
    Schaltplaneditor hinterlassen hat -- ab hier zeigt jeder Diff
    ausschliesslich die Umbauten am Schaltplan selbst.
    Ausserdem aus der Versionierung genommen:
    *.lck KiCads Sperrdatei war versehentlich eingecheckt. Sie
    entsteht beim Oeffnen und sagt nur, dass gerade jemand
    die Datei auf hat -- fuer alle anderen wertlos.
    .history/ Dateihistorie der Editor-Erweiterung.
    pcb/Bilder/ Screenshots zum Durchsehen, gleiche Kategorie wie
    pcb/_render/.
    Co-A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
    [MarsRover.kicad_sch]
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2026-10-06 Schaltplan neu aufgebaut: fuenf Bereiche, 175 gezeichnete Leitungen
    Der alte Schaltplan verband alles ueber Netzlabels, die Bauteile standen
    ungeordnet auf dem Blatt. Jetzt:
    Blatt A2, fuenf beschriftete Bereiche -- Rechenkern, Motortreiber,
    Sensoren Linienerkennung, Sensoren Lage und Abstand, Signal-LEDs,
    Akku und Ladevorrichtung.
    175 gezeichnete Leitungen, 25 Knotenpunkte, NULL Netzlabels.
    Geprueft: ERC 0 Fehler, keine verwaisten Leitungen, keine Ueberlappungen,
    Netzliste knotengenau gegen den Entwurf abgeglichen. Zwei echte
    Zeichenfehler behoben -- Leitungen liefen durch die Gehaeuse von U2 und U5.
    Die LED-MOSFETs entfallen wieder: ESP32-WROOM-32 v3.8, Tabelle 14 nennt
    I_OH typi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
    [MarsRover.kicad_sch]
2026-10-06 Schaltplan: Layout des Nutzers uebernommen, zwei Bruchstellen repariert
    Der in KiCad umgestellte und lesbar gemachte Schaltplan kam elektrisch
    kaputt zurueck. Zwei Ursachen, beide behoben, Layout unveraendert
    uebernommen:
    1. Blatt-UUID und Bauteil-Eintraege zeigten auf verschiedene UUIDs.
    KiCad hatte beim Speichern neue Instanzpfade geschrieben, ohne die
    uuid des Blattes mitzuziehen. Folge: der Netzlisten-Export fand nur
    noch die drei Versorgungsnetze -- die haengen an Power-Symbolen und
    brauchen keine Instanz. Alle 48 ueber Leitungen verdrahteten Netze
    fehlten. ERC meldete das nicht, es sieht die Leitungen weiterhin.
    2. GPIO22 (I2C-SCL) war wirklich abgerissen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
    [MarsRover.kicad_sch]
2026-10-06 Entkopplung ergaenzt: C5 bis C12, Motoranschluesse als Loetaugen
    Neu, alle mit gezeichneten Leitungen eingefuegt:
    C5 100n parallel zu C1/C2 an der 5-V-Schiene
    C6 10u/25V am ESP32, VIN gegen Masse
    C7 100n am ESP32, VIN gegen Masse
    C8 100n am ESP32, 3V3 gegen Masse
    C9 100n an OS1
    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
    [MarsRover.kicad_sch]
2026-10-06 Stueckliste nachgezogen, Fussabdruecke fuer alle Bauteile zugewiesen
    Stueckliste:
    - Rechenkern war noch auf DevKit V1 30-Pin, jetzt DevKitC V4 38-Pin
    - C1 auf 100u/10V, C2 auf 10u/25V, C5 neu
    - neuer Abschnitt 5a Entkopplung mit C6 bis C10
    - C11/C12 im Motortreiber, samt Begruendung warum sie nach GND gehen
    und nicht ueber die Motorklemmen
    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
    [MarsRover.kicad_sch]
2026-10-06 Platine angelegt: 45 Fussabdruecke, 2 Lagen, 1,0 mm, grobe Platzierung
    MarsRover.kicad_pcb aus dem Schaltplan erzeugt. 45 Fussabdruecke,
    151 Pads, 114 Netzzuweisungen. Zwei Kupferlagen, wie gewuenscht.
    Platinendicke von 1,6 auf 1,0 mm gesetzt (Doku/04: spart 2,2 g bei
    gleichem Preis).
    Umriss VORLAEUFIG 60 x 52 mm auf Edge.Cuts. Die bisher geplanten
    50 x 38 mm sind nicht haltbar: der Fussabdruck des DevKitC V4 misst
    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
    [MarsRover.kicad_pcb]
2026-10-06 Layout Version A: 70 x 52 mm, alles platziert, null ernste DRC-Fehler
    Schaltplan: die doppelt vergebenen Power-Referenzen #PWR34 und #PWR36
    entwirrt. Mein Einfuegeskript hatte mit dem Zaehlen neu angefangen,
    obwohl der urspruengliche Aufbau diese Nummern schon benutzte. Das war
    der Fehler, den KiCads Annotation gemeldet hat. ERC weiter 0 Fehler.
    Platine:
    Kontur 70 x 52 mm (Version A). Breiter heisst mehr Lenkautoritaet --
    das Lenkmoment ist Vibrationskraft mal Abstand zur Laengsachse.
    Entwurfsregeln: Abstand 0,2 mm, Bahn 0,4 mm, minimal 0,25 mm,
    Durchkontaktierung 0,8/0,4 mm.
    Netzklasse "Leistung" mit 1,0 mm fuer +5V, +3V3, GND, Akkupfad und
    die beiden Motorzweige.
    Anordnung: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
    [MarsRover.kicad_pcb, MarsRover.kicad_sch]
2026-10-07 MT3608: Poti raus, Festteiler 110k/15k rein
    Vor dem Einbau des Moduls. Zwei Gruende: das Poti ist das hoechste Bauteil
    und steht bei senkrechter Montage im Weg, und ein Schleifkontakt auf einem
    Vibrationsfahrzeug verstellt sich -- im schlechten Fall nach oben, und dann
    haengt das DevKit an mehr als 5 V.
    0,6 V x (1 + 110k/15k) = 5,00 V ueber die FB-Referenz des MT3608.
    Dokumentiert ist auch der Fallstrick: der werkseitige untere
    Rueckkopplungswiderstand muss raus, sonst liegt er parallel zu den 15k.
2026-10-07 Platine geroutet: 27 von 27 Netzen, null unverbundene Elemente
    Geroutet mit KiCadRoutingTools (A*-Router mit Rust-Kern, MIT, headless auf
    der .kicad_pcb). 101 Durchkontaktierungen, Massflaeche auf B.Cu als eine
    zusammenhaengende Insel. DRC: 0 Abstandsverstoesse, 0 Kurzschluesse,
    0 unverbundene Elemente; es bleiben nur Siebdruck-Kosmetik und die
    gewollten Courtyard-Ueberlappungen unter dem gesockelten DevKit.
    Platzierung nachgezogen:
    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
    [MarsRover.kicad_pcb, MarsRover.kicad_sch]
2026-10-07 U5 an die Hinterkante: der Micro-USB des DevKits war blockiert
    Pad 1 von U1 ist 3V3 (Antennenende), Pad 19 ist 5V -- der USB sitzt also am
    +x-Ende bei x = 154, mittig auf der Modulbreite bei y = 85. U5 stand mit
    y 81,2..88,8 genau davor.
    U5 jetzt bei y 97,0..104,62, Gehaeusevorderkante 95,2 -- gut 4 mm Luft zum
    Steckergehaeuse. Damit das ging, mussten R16/R17 (Spannungsteiler VBAT ->
    GPIO39) von x 156,5/160,5 nach x 150/154 wandern; als 0805 duerfen sie
    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
    [MarsRover.kicad_pcb]
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2026-10-07 Siebdruck aufgeraeumt und Fertigungsdaten erzeugt
    Bestueckungsdruck von 96 Verstoessen auf null:
    - 45 Wertefelder ausgeblendet (der Wert steht in der Stueckliste; das
    Wertefeld von U1 lag auf dem Pad von C7)
    - die 38 Pinnamen des DevKitC-Footprints auf F.Fab verschoben. Sie stehen
    auf 2,54 mm Raster, sind 0,7 mm hoch und jeder Name ist laenger als sein
    Rastermass -- gedruckt ein Schmierer, und das Modul deckt sie zu, waehrend
    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
    [MarsRover-bestueckung.csv, MarsRover-platine.step, MarsRover-stueckliste.csv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]
2026-10-07 Waermefallen an der Massflaeche
    Die Flaeche hing fest an den Pads (connect_pads yes, so vom Router gesetzt).
    Eine 70 x 52 mm grosse Kupferflaeche zieht beim Handloeten die Waerme
    schneller ab, als ein Loetkolben sie nachliefert -- das gibt kalte
    Loetstellen, die beim Messen oft noch leitend wirken und erst bei Vibration
    ausfallen. Auf diesem Geraet also garantiert.
    Jetzt Waermefallen: Spalt 0,4 mm, vier Stege zu 0,5 mm. Die vorhandenen
    Werte waren mit je 0,2 mm zu knapp und wurden ohnehin nicht benutzt.
    Betroffen sind die 20 bedrahteten Masse-Pads, die die Flaeche direkt
    beruehren. Die 16 SMD-Masse-Pads auf der Oberseite beruehren sie gar nicht,
    sie haengen ueber eine kurze Leitung und ein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
    [MarsRover-platine.step, MarsRover.kicad_pcb]
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
